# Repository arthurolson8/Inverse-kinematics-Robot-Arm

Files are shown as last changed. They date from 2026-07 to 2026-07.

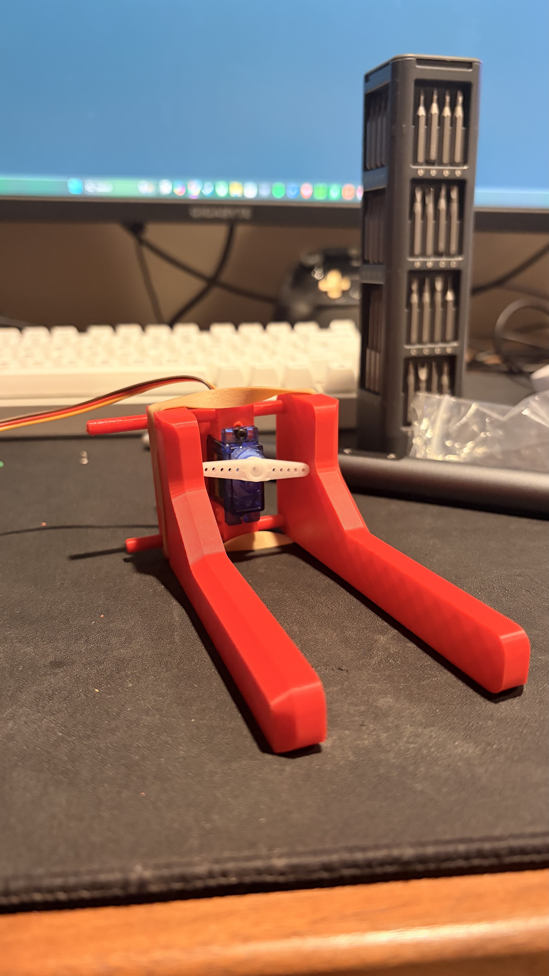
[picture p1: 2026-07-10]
Design Process/Iterations/Gripper/IMG_4110.jpeg

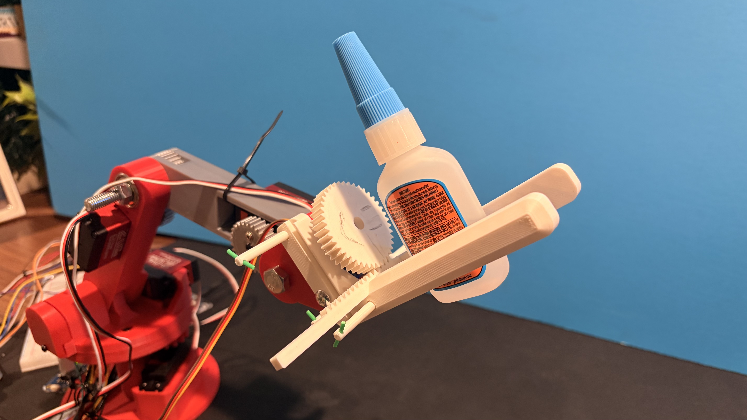
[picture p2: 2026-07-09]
Images/IMG_4085.jpeg

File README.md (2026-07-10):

# Inverse Kinematics Robot Arm

## Overview

This project is a custom-designed 4-degree-of-freedom robotic arm built from the ground up using Solidworks, Arduino, and 3D-printed components. The goal of this project is to develop practical skills in mechanical design, embedded systems, robotics, and control algorithms, and also feel like Tony Stark.
The robot is designed to perform precise pick-and-place operations using inverse kinematics, high-torque servo motors, and a custom rack-and-pinion gripper with auto table leveling.

---

## Objectives

- Design a fully custom robotic arm in SolidWorks
- Manufacture structural components using 3D printing
- Develop an Arduino-based control system
- Implement forward and inverse kinematics
- Create a modular robot that can be expanded with sensors and computer vision (hopefully)
- Document the engineering design process from concept to finished prototype

---

## Features

- Custom 3D-printed mechanical design
- 4 Degrees of Freedom
- Bearing-supported base, shoulder, elbow, and wrist joints
- High-torque DS3218 servos
- SG90 rack-and-pinion gripper
- Arduino Uno R4 WiFi controller
- PCA9685 16-channel servo driver (have not integrated yet)
- Manual joystick control
- Modular electronics design
- Expandable software architecture

Planned Features

- Cartesian position control
- Inverse kinematics
- Autonomous pick-and-place
- Computer vision using OpenCV
- Camera-based object detection
- Object size estimation
- Automatic gripping
- Motion recording and playback

---

### Hardware / Mechanical

- Custom CAD using SolidWorks
- Custom 3D Printed parts using PLA
- 2 M8 60mm Bolts
- 1 M8 50mm Bolt
- 2 M8 Nuts
- Various sizes of M2 and M3 bolts and nuts
- M2 and M8 threaded inserts
- 8 608 ZZ bearings

### Electronics

- Arduino Uno R4 WiFi
- PCA9685 Servo Driver
- breadboard
- 4× DS3218 20kg·cm Servos
- 2× SG90 Micro Servos
- Three Dual-Axis Joysticks (only 2 used for final controls)
- External 5V 10A Power Supply

---

## Software

- Arduino IDE
- C++
- Solidworks
- Git
- GitHub

Future Software

- Python
- OpenCV
- Serial Communication
- Autonomous Motion Planning

---

## Mechanical Design

The arm uses bearing-supported rotating joints to reduce servo loading and improve structural rigidity. The base, elbow, and wrist joints are gear-driven with a 1:1 ratio, while the shoulder joint is direct drive. For the final version of the gripper, I opted for a Rack and pinion design after 2 other past versions.

Major design goals include

- Lightweight construction
- High stiffness
- Modular assemblies
- Easy maintenance
- Minimal backlash
- Manufacturable using hobby-grade 3D printers

---

## Project Status

Current Progress

- [x] Overall robot architecture completed
- [x] CAD design completed
- [x] Mechanical design iterations
- [x] Gear train prototypes
- [x] Manufacturing
- [x] Assembly
- [x] Wiring
- [x] Servo calibration
- [x] Joystick control
- [x] Forward kinematics
- [x] Inverse kinematics
- [ ] Autonomous pick-and-place w computer vison

---

## Design Iterations

Version 1
- Initial geared shoulder joint (gears slipped) with parallel arm gripper
- bearing-supported joints
- heat set inserts

Version 2
- Reinforced the servo mount and made the shoulder direct drive
- Made a gripper with a closing mechanism supported by rubber bands (broke servo)

Version 3 (Current)
- Improved structural rigidity
- Rack-and-pinion gripper
- Modular arm assemblies

Future Versions
- Computer vision
- Force sensing
- Autonomous object sorting

---

## Lessons Learned

Throughout this project, I have gained experience in

- Mechanical design
- CAD modeling
- Design iteration
- Failure analysis
- Rapid prototyping
- Embedded programming
- Robotics
- Electronics integration
- Manufacturing constraints
- Engineering documentation

---

## Possible Future Improvements

- Computer vision
- Camera calibration
- Automatic object detection
- Object size estimation
- Adaptive gripping
- Motion planning
- Closed-loop control
- Force sensing

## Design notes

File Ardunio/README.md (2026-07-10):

# Software Architecture

The robot is controlled by a custom Arduino program written in C++ using the Arduino IDE. Rather than relying on existing robotic arm frameworks, the software was developed specifically for this robot's mechanical design, servo configuration, and joint geometry.

The software is organized around modular subsystems responsible for robot configuration, joint control, joystick input, calibration, gripper control, and inverse kinematics. During development these modules were combined into a single Arduino sketch (`MARK_IV_IK_ARM.ino`) to simplify deployment and debugging.

---
## Control Flow Chart

User Input (Joystick or Camera)
            │
            ▼
Desired Position (X, Y, Z)
            │
            ▼
Inverse Kinematics Solver
            │
            ▼
Joint Angles
            │
            ▼
Servo Calibration Offsets
            │
            ▼
Motion Limiting & Safety Checks
            │
            ▼
Servo Commands
            │
            ▼
Physical Robot Movement

---
# Software Design Philosophy

The primary goals during development were:

- Modular and readable code
- Easy servo calibration
- Smooth joint motion
- Expandability for inverse kinematics
- Support for future autonomous operation

Instead of directly writing servo positions throughout the program, each joint is treated as an independent object with its own limits, speed, home position, and calibration settings. This makes it possible to modify individual joints without rewriting the entire control system.

---

# Robot Configuration

The first section of the program defines the hardware configuration of the robot.

This includes:

- Servo pin assignments
- Joystick analog pins
- Joystick button pins
- Servo home positions
- Motion limits
- Servo directions
- Servo speeds
- Servo pulse widths
- Servo travel ranges

Separating these values from the rest of the code makes it possible to mechanically redesign the robot without changing the control algorithms.

---

# Joint Control

Each joint maintains its own state including:

- Current position
- Target position
- Home position
- Minimum angle
- Maximum angle
- Maximum movement speed
- Servo direction
- Servo type

Every program loop updates each joint independently.

Rather than instantly jumping to the requested angle, each joint moves toward its target position at a controlled speed. This produces smoother motion, reduces shock loading on the gears, and decreases current spikes.

---

# Joystick Control

The robot is manually controlled using three dual-axis joysticks. (But only 2 in Inverse kinematics mode)

The joysticks provide analog control inputs corresponding to the robot's six degrees of freedom.

Each joystick value is read using Arduino analog inputs.

The joystick values are converted into incremental motion commands rather than absolute positions. This allows the servos to hold their current position whenever the joystick returns to center.

Deadbands are implemented around the joystick center position to eliminate unwanted drift caused by analog noise.

---

# Servo Calibration

One of the largest challenges during development was aligning the mathematical model of the robot with the physical servo positions.

Although inverse kinematics computes joint angles mathematically, every servo is mounted differently and has its own mechanical zero position.

To solve this problem, calibration offsets were introduced.

The calibration process consists of:

1. Moving each joint into a known mechanical reference position.
2. Recording the raw servo angle.
3. Comparing the measured position to the desired mathematical angle.
4. Computing an offset for each servo.
5. Applying the offset whenever inverse kinematics calculates a new joint angle.

This allows the inverse kinematics model to remain independent of the physical mounting orientation of each servo.

---

# Motion Limits

Every servo is constrained to safe operating limits.

Before commanding any movement, the requested angle is clamped between predefined minimum and maximum values.

This prevents:

- Mechanical interference
- Gear damage
- Servo overtravel
- Wiring collisions

Software limits provide an additional layer of protection beyond the physical design.

---

# Inverse Kinematics

The long-term objective of the software is to allow the robot to move to any point within its reachable workspace using Cartesian coordinates.

Instead of manually controlling every servo, the operator specifies the desired end-effector position.

For example:

X = 180 mm

Y = 120 mm

Z = 90 mm

The inverse kinematics algorithm calculates the required joint angles for:

- Base rotation
- Shoulder
- Elbow
- Wrist pitch

Wrist Pitch is locked to be level with the table until a button is pressed then it is free to move. When the lick is engaged again it snaps back to normal horizontal position.

These calculated angles are then converted into calibrated servo commands before being sent to the motors.

This approach separates robot motion from individual servo control, making future autonomous operation possible.

---

# Future Autonomous Operation

The software architecture has been designed with future expansion in mind.

Planned capabilities include:

- Camera-based object detection
- Object size estimation
- Automatic pick-and-place
- Motion recording and playback
- Vision-guided positioning
- Adaptive gripping
- Closed-loop control

The modular design allows these features to be added without restructuring the existing software.

---

# Development Process

This software was developed iteratively alongside the mechanical design of the robot.

As each mechanical subsystem was redesigned, the software was updated to accommodate new joint limits, calibration offsets, and transmission configurations.

Several iterations were required before achieving reliable and repeatable motion due to:

- Servo mounting changes
- Gear ratio modifications
- Shoulder joint redesigns
- Mechanical backlash
- Servo calibration refinement

Developing the software in parallel with the hardware provided valuable experience integrating mechanical, electrical, and embedded software systems into a complete robotic platform.

---

# Lessons Learned

This project provided practical experience in:

- Embedded C++ programming
- Arduino development
- Robot kinematics
- Servo calibration
- Motion control
- Electronics integration
- Mechanical-software integration
- Iterative engineering design
- Debugging embedded systems

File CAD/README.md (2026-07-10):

Here are my current CAD files with assemblies and some pictures

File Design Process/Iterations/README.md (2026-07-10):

Overall Design Process
-
My main redesigns happened with the shoulder and the gripper. I had about 3 versions of the gripper and around 4-5 printed shoulder joint designs, and that is why you see the change from silver to red as the robot evolved. The white was just cause I felt like it though.

The current folder holds all my deaign choice explanations besides the gripper and shoulder.

Check out these folders to see my in detail explanations with pictures!

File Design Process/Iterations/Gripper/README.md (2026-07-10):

Gripper Design Process
-
My first Version was a parallel style gripper with 2 gears attached to the gripper fingers that are moved by one servo, this design looked cool but overall had too much slop. Even though it could hold on to things effectivly, the far end of the fingers were a bit weak, it was hard on the servo and the 8 M3 screws nuts would unscrew themselves automatically when the gripper was used, and I didnt want to permanently attatch them with locktight because then the servo would be stuck in there forever.

V1 Problems
- weak towards far end of fingers
- hard on servo

For my second version I made 2 free moving fingers on either side of the center wrist mount that were attached via 3d printed pins. The plan was to have a rubber band around the 2 fingers and the servo arm would be in the middle and extend horizontally to open it and go vertical to close. Unfortunately even if I used the smallest rubber band I could find, it was too much for the servo to open reliably.

V2 Problems
- too much force on servo
- broken servo

For the 3rd Version I slightly modified the V2 by adding a rack and pinon style gear set up to do the open/closing mechanism and mounted the rack to one finger and mounted the other finger to the side of the wrist mount.

V3 problems
- only has one set distance to open to atm
  
Possible solutions
- force sensor on inside of fingers

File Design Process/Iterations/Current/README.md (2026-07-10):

Current Design explanations
-
Because I wanted bearing supported joints for all of the links and base, I decided to make most of the joints gear driven because I could not think of a compact way to have it direct driven with M8 bolts as the joint axises.

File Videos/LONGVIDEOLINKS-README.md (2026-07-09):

Here is a youtube link for the DEMO of the Current Arm :
https://m.youtube.com/watch?v=HJ-uZ0-45NE&pp=ygUhSW52ZXJzZSBraW5lbWF0aWNzIHJvYm90IG1hcmsgSVYg&ra=m

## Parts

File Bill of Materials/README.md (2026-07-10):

# Bill of Materials (BOM)

| Component | Quantity | Purpose |
|---|:---:|---|
| Arduino Uno R4 WiFi | 1 | Main microcontroller |
| PCA9685 16-Channel Servo Driver | 1 | Controls multiple servos |
| DS3218 20kg·cm 270° Servo Motors | 4 | Base, shoulder, elbow, and wrist pitch joints |
| SG90 Micro Servo Motors | 2 | Wrist roll and gripper |
| Dual-Axis Joystick Modules | 3 | Manual robot control |
| 5V 10A DC Power Supply | 1 | External power source for servos |
| DC Barrel Jack Connector Kit | 1 | Power supply connection |
| Breadboard & Jumper Wire Kit | 1 | Prototyping electronics |
| Heat Shrink Tubing Assortment | 1 | Wire insulation and cable management |
| 608ZZ Ball Bearings | 10 | Joint support and reduced friction |
| M3 Screw, Nut & Washer Assortment | 1 Kit | Primary fasteners for printed parts |
| M2 Screw & Nut Assortment | 1 Kit | Small hardware for electronics and gripper assembly |
| M3 Brass Heat-Set Threaded Inserts | 100 | Durable threaded mounting points in 3D printed parts |
| M2 Brass Heat-Set Threaded Inserts | 1 Kit | Threaded inserts for smaller printed components |
| $10 Soldering Iron | 1 | Assembly and electrical connections |

---

## Software

- Arduino IDE
- Solidworks
- GitHub

### Planned Hardware

- Logitech C270 Webcam

### Planned Software

- Python
- OpenCV

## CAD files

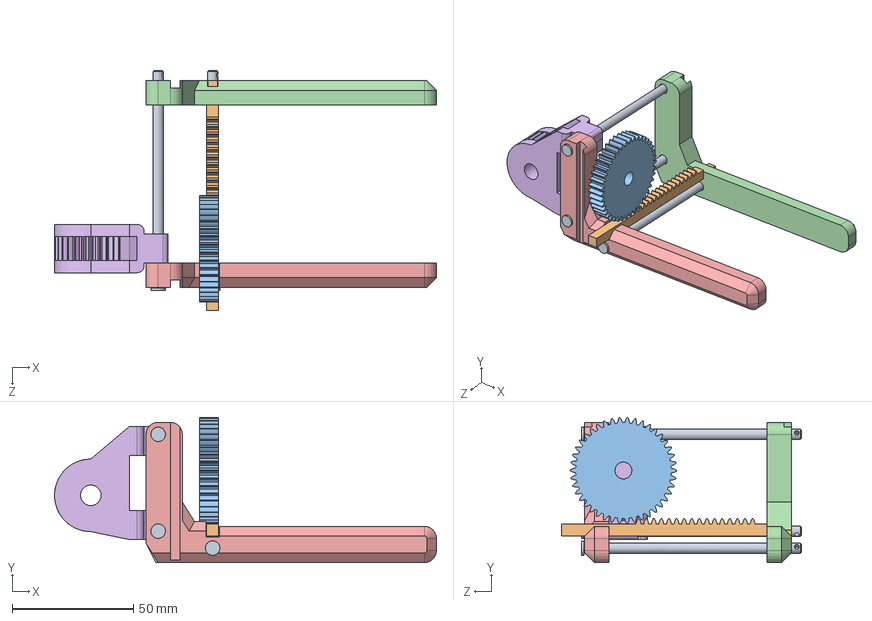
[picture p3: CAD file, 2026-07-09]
Design Process/Iterations/Gripper/NV2 Gripper assem.SLDASM
157.8 x 60.0 x 99.2 mm
Wrist Joint V3
Gripper finger R
Gripper finger L
Gripper gear
Gripper Rack
Gripper pin V2 x 3

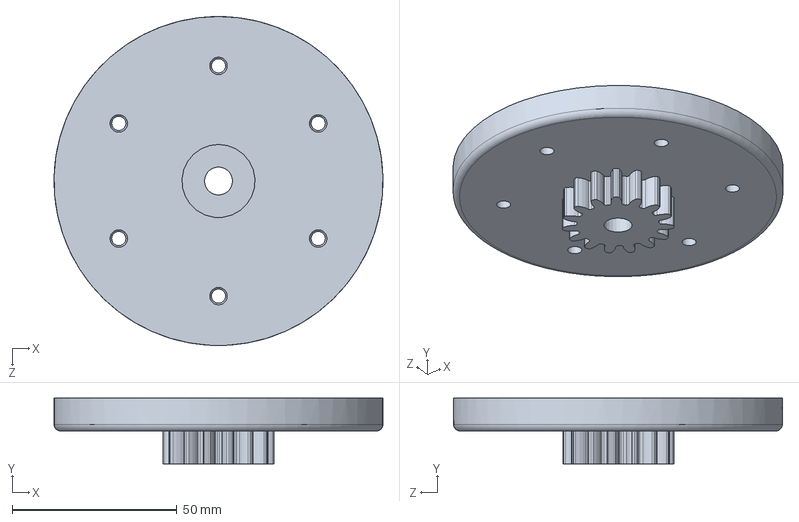
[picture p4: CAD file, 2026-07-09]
CAD/Base/NV1 Base mount.SLDPRT
100.0 x 20.0 x 100.0 mm

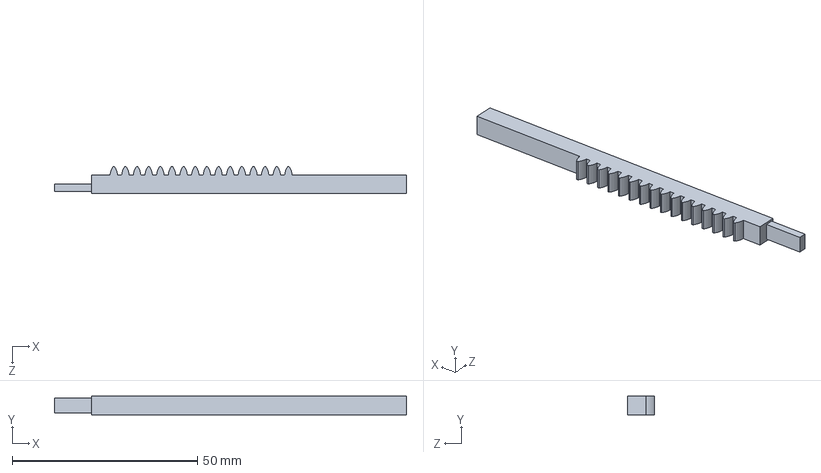
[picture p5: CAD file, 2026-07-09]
CAD/Gripper/Gripper Rack.SLDPRT
95.0 x 5.00 x 7.25 mm

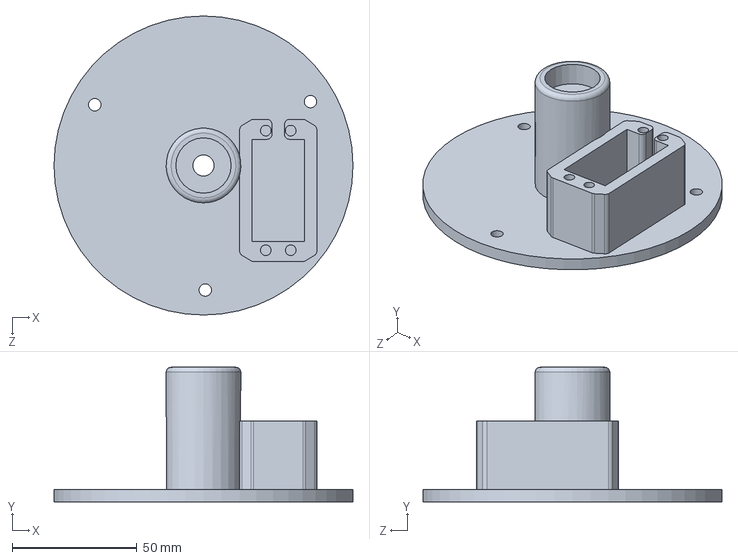
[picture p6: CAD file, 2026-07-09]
CAD/Base/NV1 Standing Base.SLDPRT
120.0 x 54.0 x 120.0 mm

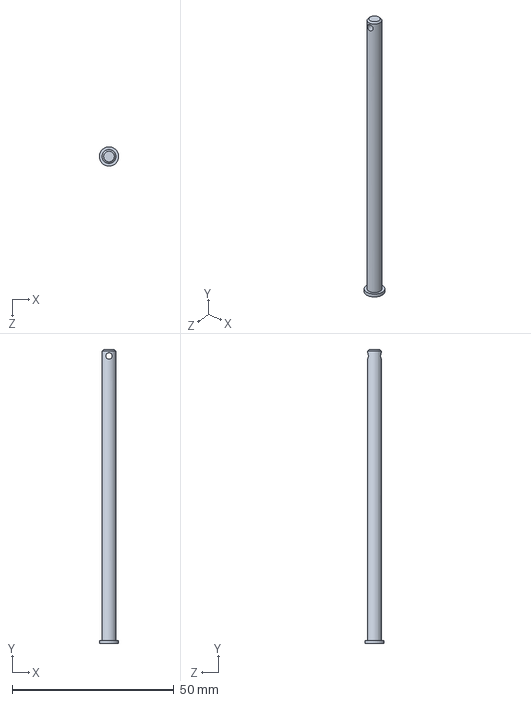
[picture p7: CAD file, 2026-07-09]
CAD/Gripper/Gripper pin V2.SLDPRT
5.99 x 91.0 x 6.00 mm

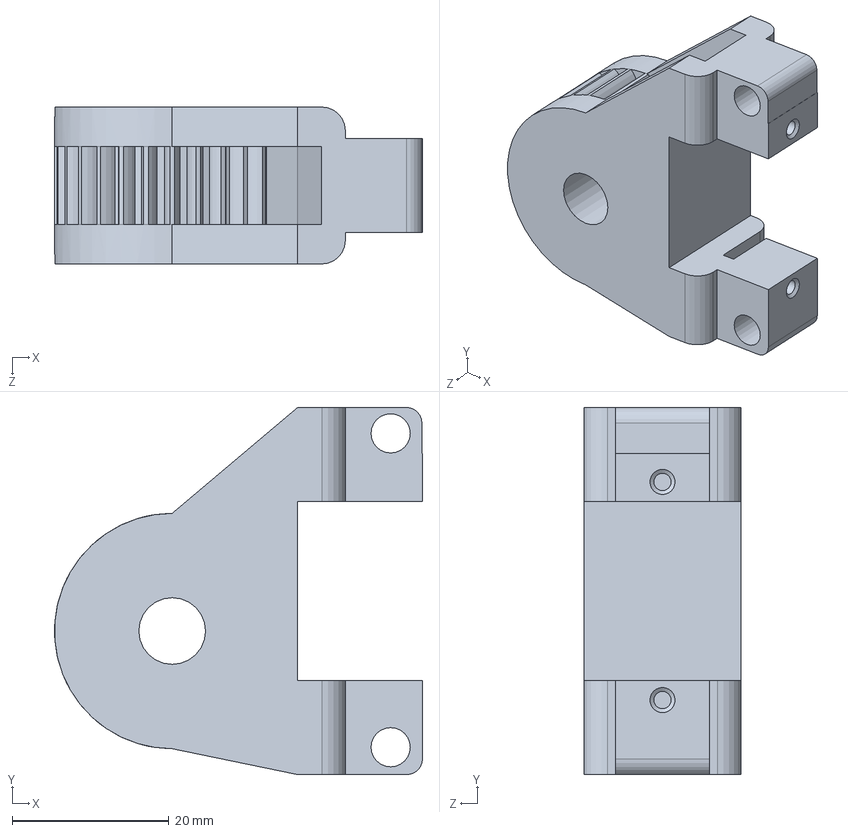
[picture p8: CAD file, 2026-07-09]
CAD/Arm/Wrist Joint V3.SLDPRT
46.9 x 46.8 x 20.0 mm

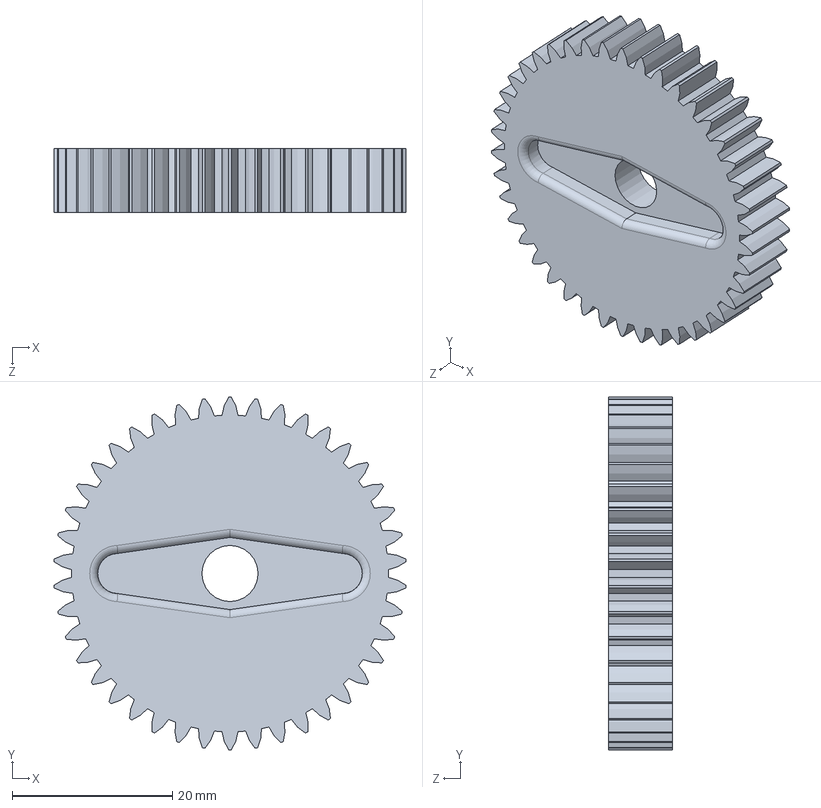
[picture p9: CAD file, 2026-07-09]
CAD/Gripper/Gripper gear.SLDPRT
43.9 x 44.0 x 8.00 mm

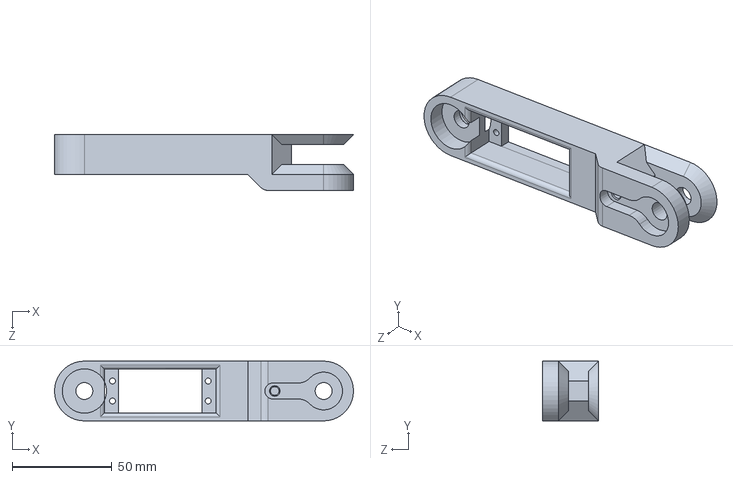
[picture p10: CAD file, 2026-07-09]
CAD/Arm/Direct Drive Bicep Link V1F.SLDPRT
150.0 x 30.0 x 28.0 mm

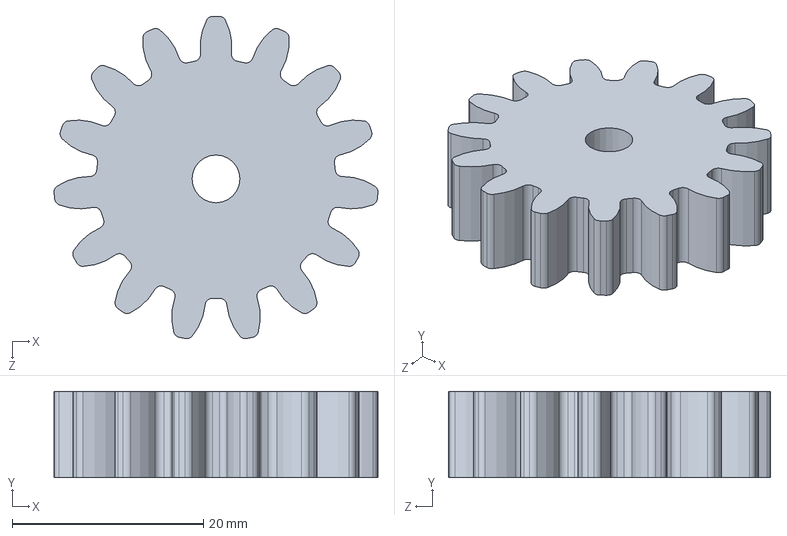
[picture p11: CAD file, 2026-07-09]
CAD/Base/NV1 Base Gear.SLDPRT
33.9 x 9.00 x 33.7 mm

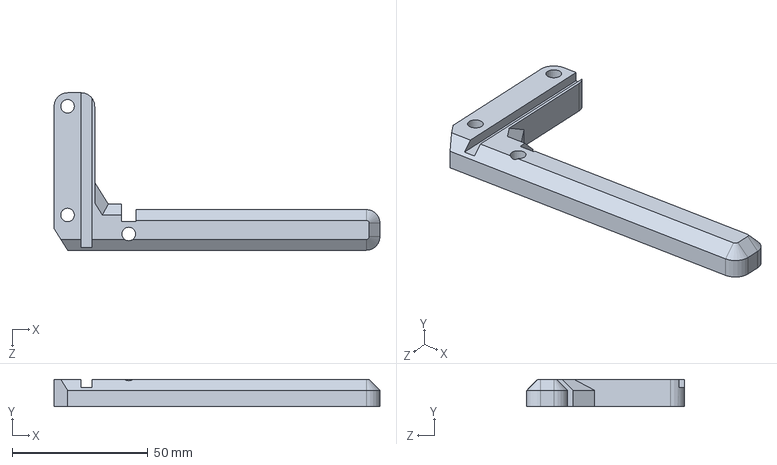
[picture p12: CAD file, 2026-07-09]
CAD/Gripper/Gripper finger R.SLDPRT
120.0 x 10.0 x 58.0 mm

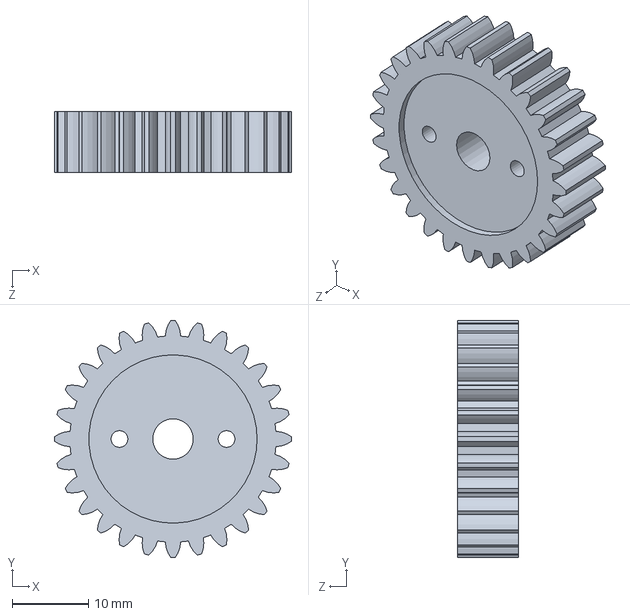
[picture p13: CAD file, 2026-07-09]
CAD/Arm/elbow servo gear.SLDPRT
31.0 x 31.0 x 8.00 mm

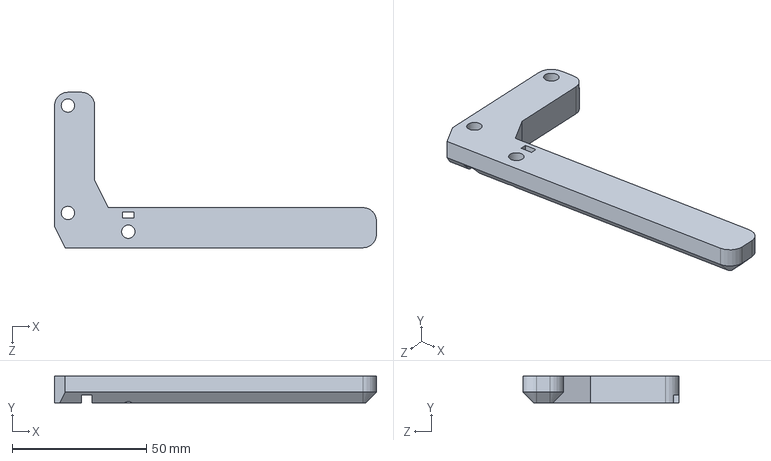
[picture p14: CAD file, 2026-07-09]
CAD/Gripper/Gripper finger L.SLDPRT
120.0 x 10.0 x 58.0 mm

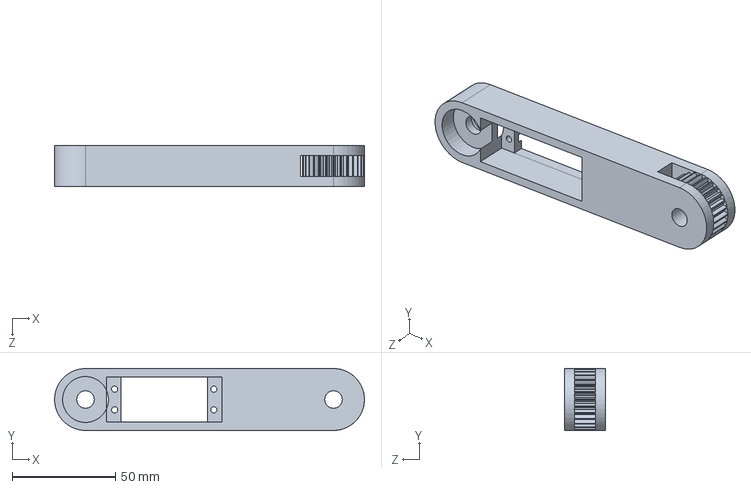
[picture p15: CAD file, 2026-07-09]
CAD/Arm/Forearm Link.SLDPRT
150.0 x 30.0 x 20.0 mm

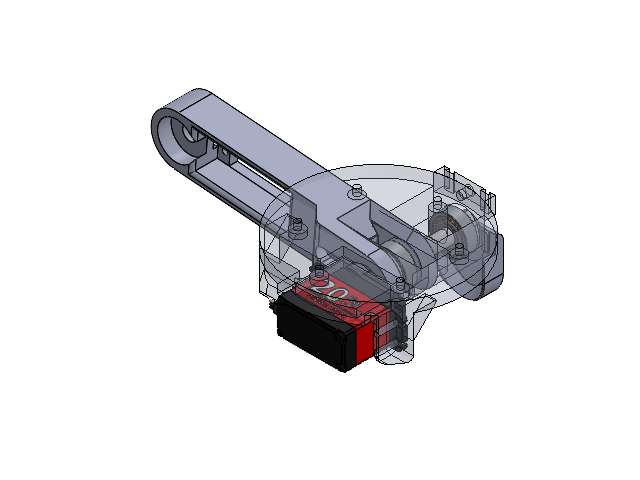
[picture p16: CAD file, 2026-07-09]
Design Process/Iterations/Shoulder Joint/Direct drive Assem.SLDASM
Direct Drive Shoulder Mount V1F
Direct Drive Bicep Link V1F
DS3218MG MS24 Digital Servo 270
p BEARING, METRIC 600 MINIATURE SERIES, DOUBLE-SHIELDED — template Copy x 2
formed hex screw_am
Direct Drive Bolt Cover V1F

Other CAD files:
CAD/Arm/Direct drive Arm Assem.SLDASM
Design Process/Iterations/Gripper/V2 Gripper assem.SLDASM
Design Process/Iterations/Shoulder Joint/Gear shoulder assem.SLDASM
CAD/Base/NV Base Assem.SLDASM
CAD/Arm/Direct Drive Bolt Cover V1F.SLDPRT
CAD/Arm/Direct Drive Shoulder Mount V1F.SLDPRT
Design Process/Iterations/Gripper/OLD V2 Gripper assem.SLDASM
Design Process/Iterations/Old CAD files/OLDARM/Bicep Link V2.SLDPRT
Design Process/Iterations/Old CAD files/OLDARM/Bicep Link.SLDPRT
Design Process/Iterations/Old CAD files/OLDARM/Shoulder base mount V2.SLDPRT
Design Process/Iterations/Old CAD files/OLDARM/Shoulder base mount V4.SLDPRT
Design Process/Iterations/Old CAD files/OLDARM/Shoulder base mount.SLDPRT
Design Process/Iterations/Old CAD files/OLDARM/Wrist Joint gear V2.SLDPRT
Design Process/Iterations/Old CAD files/OLDARM/Wrist Joint gear.SLDPRT
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

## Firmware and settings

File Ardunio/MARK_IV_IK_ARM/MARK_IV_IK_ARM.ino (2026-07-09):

//====================================================================
// Robot_Masterfile.ino
// Single-file build: all modules merged into one sketch file.
// (Config / Joint / Controller / Gripper / Calibration)
//====================================================================

#include <Arduino.h>
#include <Servo.h>
#include <EEPROM.h>
#include <Arduino_Modulino.h>


//====================================================================
// CONFIG
//====================================================================
const byte NUM_JOINTS = 6;
//====================================================
//                  LIBRARIES
//====================================================

#include <Arduino.h>

//====================================================
//                SERVO PINS
//====================================================

const byte BASE_PIN         = 0;
const byte SHOULDER_PIN     = 5;
const byte ELBOW_PIN        = 9;
const byte WRIST_PITCH_PIN  =11;
const byte GRIPPER_PIN   = 13;
const byte UNUSED_SERVO_PIN      = 12;

//====================================================
//             JOYSTICK ANALOG PINS
//====================================================

// Joystick 1
const byte J1_X = A0;
const byte J1_Y = A1;

// Joystick 2
const byte J2_X = A2;
const byte J2_Y = A3;

// Joystick 3
const byte J3_X = A4;
const byte J3_Y = A5;

//====================================================
//          JOYSTICK BUTTON PINS (OPTIONAL)
//====================================================

const byte J1_SW = 3;
const byte J2_SW = 5;
const byte J3_SW = 7;

//====================================================
//              SERVO HOME POSITIONS
//====================================================

// These are the positions the robot moves to on startup.
// Adjust after assembling the arm.

const float BASE_HOME         = 135.0;
const float SHOULDER_HOME     = 156.0;
const float ELBOW_HOME        = 118.0;
const float WRIST_PITCH_HOME  = 206.0;
const float GRIPPER_HOME   = 100.64; // closed
const float UNUSED_SERVO_HOME      = 30.0;

//====================================================
//                SERVO LIMITS
//====================================================

// Degrees

const float BASE_MIN = 0;
const float BASE_MAX = 270;

const float SHOULDER_MIN = 50;
const float SHOULDER_MAX = 220;

const float ELBOW_MIN = 40;
const float ELBOW_MAX = 243;

const float WRIST_PITCH_MIN = 56;
const float WRIST_PITCH_MAX = 223;

const float GRIPPER_MIN = 0;
const float GRIPPER_MAX = 123; // open

const float UNUSED_SERVO_MIN = 20;
const float UNUSED_SERVO_MAX = 105;

//====================================================
//            SERVO DIRECTION
//====================================================

// false = normal
// true = reversed

const bool BASE_REVERSE         = false;
const bool SHOULDER_REVERSE     = false;
const bool ELBOW_REVERSE        = false;
const bool WRIST_PITCH_REVERSE  = false;
const bool GRIPPER_REVERSE   = false;
const bool UNUSED_SERVO_REVERSE      = false;

//====================================================
//              MAX SERVO SPEED
//====================================================

// Degrees moved per update.
// Larger value = faster motion.

const float BASE_SPEED         = .5;
const float SHOULDER_SPEED     = 1;
const float ELBOW_SPEED        = 1.0;
const float WRIST_PITCH_SPEED  = 1.1;
const float GRIPPER_SPEED   = 2;
const float UNUSED_SERVO_SPEED      = 2.0;


//====================================================
// Servo Types
//====================================================

// DS3218 Servos
const float DS3218_RANGE = 270.0;

// SG90 Servos
const float SG90_RANGE = 180.0;


//====================================================
// Pulse Widths
//====================================================

// DS3218
const int DS3218_MIN_US = 500;
const int DS3218_MAX_US = 2500;

// SG90
const int SG90_MIN_US = 500;
const int SG90_MAX_US = 2400;

//====================================================
//             JOYSTICK SETTINGS
//====================================================

const int DEADZONE = 60;

// These will be calibrated automatically
// during startup.

extern int J1_X_CENTER;
extern int J1_Y_CENTER;

extern int J2_X_CENTER;
extern int J2_Y_CENTER;

extern int J3_X_CENTER;
extern int J3_Y_CENTER;

//====================================================
//             SERVO PWM CALIBRATION
//====================================================

// Most DS3218 servos work well with these.
// We'll fine tune later if necessary.

const int SERVO_MIN_US = 500;
const int SERVO_MAX_US = 2500;

//====================================================
//               DEBUG OPTIONS
//====================================================

const bool ENABLE_SERIAL_DEBUG = true;


//====================================================
// Number of Joints
//====================================================


// Joint Numbers

enum JointID
{
    BASE = 0,
    SHOULDER,
    ELBOW,
    WRIST_PITCH,
    GRIPPER,
    UNUSED_SERVO
};
//====================================================
// JOINT CONFIGURATION (ARRAY-BASED)
//====================================================

const byte servoPins[NUM_JOINTS] =
{
    BASE_PIN,
    SHOULDER_PIN,
    ELBOW_PIN,
    WRIST_PITCH_PIN,
    GRIPPER_PIN,
    UNUSED_SERVO_PIN
};

const float homePositions[NUM_JOINTS] =
{
    BASE_HOME,
    SHOULDER_HOME,
    ELBOW_HOME,
    WRIST_PITCH_HOME,
    GRIPPER_HOME,
    UNUSED_SERVO_HOME
};

const float minAngles[NUM_JOINTS] =
{
    BASE_MIN,
    SHOULDER_MIN,
    ELBOW_MIN,
    WRIST_PITCH_MIN,
    GRIPPER_MIN,
    UNUSED_SERVO_MIN
};

const float maxAngles[NUM_JOINTS] =
{
    BASE_MAX,
    SHOULDER_MAX,
    ELBOW_MAX,
    WRIST_PITCH_MAX,
    GRIPPER_MAX,
    UNUSED_SERVO_MAX
};

const float servoSpeeds[NUM_JOINTS] =
{
    BASE_SPEED,
    SHOULDER_SPEED,
    ELBOW_SPEED,
    WRIST_PITCH_SPEED,
    GRIPPER_SPEED,
    UNUSED_SERVO_SPEED
};

const bool servoReverse[NUM_JOINTS] =
{
    BASE_REVERSE,
    SHOULDER_REVERSE,
    ELBOW_REVERSE,
    WRIST_PITCH_REVERSE,
    GRIPPER_REVERSE,
    UNUSED_SERVO_REVERSE
};

const float servoRange[NUM_JOINTS] =
{
    DS3218_RANGE,
    DS3218_RANGE,
    DS3218_RANGE,
    DS3218_RANGE,
    SG90_RANGE,
    SG90_RANGE
};

const int servoMinPulse[NUM_JOINTS] =
{
    DS3218_MIN_US,
    DS3218_MIN_US,
    DS3218_MIN_US,
    DS3218_MIN_US,
    SG90_MIN_US,
    SG90_MIN_US
};

const int servoMaxPulse[NUM_JOINTS] =
{
    DS3218_MAX_US,
    DS3218_MAX_US,
    DS3218_MAX_US,
    DS3218_MAX_US,
    SG90_MAX_US,
    SG90_MAX_US
};
enum RobotMode
{
    MODE_NORMAL,
    MODE_CALIBRATION,
    MODE_IK_ARM
};

extern RobotMode currentMode;

//====================================================================
// JOINT (declaration)
//====================================================================
#include <Arduino.h>
#include <Servo.h>
class Joint
{
private:

    Servo servo;

    byte pin;

    float position;
    float homePosition;

    float minimumAngle;
    float maximumAngle;

    float speed;

    bool reverse;

    float servoRange;

    int minPulse;
    int maxPulse;

public:

    Joint();

    void begin(
        byte servoPin,
        float home,
        float minimum,
        float maximum,
        float maxSpeed,
        bool reversed,
        float rangeDegrees,
        int minMicroseconds,
        int maxMicroseconds
    );

    void update(int joystickValue, int joystickCenter);

    void write();

    void hold();

    void home();

    void setPosition(float newPosition);

    float getPosition();

    void setSpeed(float newSpeed);

    void setReverse(bool state);

    void setLimits(float minimum,float maximum);

    float getMinLimit();

    float getMaxLimit();
};

// Global robot joints
extern Joint joints[NUM_JOINTS];

//====================================================================
// JOINT (implementation)
//====================================================================
//====================================================
// Global Joint Array
//====================================================

Joint joints[NUM_JOINTS];

//====================================================
// Constructor
//====================================================

Joint::Joint()
{
    pin = 0;

    position = 90.0;
    homePosition = 90.0;

    minimumAngle = 0.0;
    maximumAngle = 180.0;

    speed = 1.0;

    reverse = false;

    servoRange = 180.0;

    minPulse = 500;
    maxPulse = 2500;
}

//====================================================
// Begin
//====================================================

void Joint::begin(
    byte servoPin,
    float home,
    float minimum,
    float maximum,
    float maxSpeed,
    bool reversed,
    float rangeDegrees,
    int minMicroseconds,
    int maxMicroseconds
)
{
    pin = servoPin;

    homePosition = home;
    position = home;

    minimumAngle = minimum;
    maximumAngle = maximum;

    speed = maxSpeed;

    reverse = reversed;

    servoRange = rangeDegrees;

    minPulse = minMicroseconds;
    maxPulse = maxMicroseconds;

    servo.attach(pin, minPulse, maxPulse);

    write();
}

//====================================================
// Update Joint
//====================================================

void Joint::update(int joystickValue, int joystickCenter)
{
    int offset = joystickValue - joystickCenter;

    if (abs(offset) <= DEADZONE)
        return;

    float multiplier =
        (float)(abs(offset) - DEADZONE) /
        (512.0 - DEADZONE);

    multiplier = constrain(multiplier, 0.0f, 1.0f);

    float movement = multiplier * speed;

    if (reverse)
        movement = -movement;

    if (offset > 0)
        position += movement;
    else
        position -= movement;

    position = constrain(position, minimumAngle, maximumAngle);
}

//====================================================
// Hold Position
//====================================================

void Joint::hold()
{
    write();
}

//====================================================
// Home Position
//====================================================

void Joint::home()
{
    position = homePosition;
    write();
}

//====================================================
// Write Servo
//====================================================

void Joint::write()
{
    int pulse = map(
        (long)(position * 10),
        0,
        (long)(servoRange * 10),
        minPulse,
        maxPulse
    );

    servo.writeMicroseconds(pulse);
}

//====================================================
// Set Position
//====================================================

void Joint::setPosition(float newPosition)
{
    position = constrain(newPosition, minimumAngle, maximumAngle);
}

//====================================================
// Get Position
//====================================================

float Joint::getPosition()
{
    return position;
}

//====================================================
// Set Speed
//====================================================

void Joint::setSpeed(float newSpeed)
{
    speed = newSpeed;
}

//====================================================
// Reverse Direction
//====================================================

void Joint::setReverse(bool state)
{
    reverse = state;
}

//====================================================
// Set Limits
//====================================================

void Joint::setLimits(float minimum, float maximum)
{
    minimumAngle = minimum;
    maximumAngle = maximum;

    position = constrain(position, minimumAngle, maximumAngle);
}

//====================================================
// Get Limits
//====================================================

float Joint::getMinLimit()
{
    return minimumAngle;
}

float Joint::getMaxLimit()
{
    return maximumAngle;
}

//====================================================================
// CONTROLLER (declaration)
//====================================================================
#include <Arduino.h>

//====================================================
//      Global joystick center values
//====================================================

extern int J1_X_CENTER;
extern int J1_Y_CENTER;

extern int J2_X_CENTER;
extern int J2_Y_CENTER;

extern int J3_X_CENTER;
extern int J3_Y_CENTER;

//====================================================
//      Functions
//====================================================

// Reads joystick centers during startup
void calibrateJoysticks();

// Optional debug print
void printJoystickValues();

//====================================================================
// CONTROLLER (implementation)
//====================================================================
//====================================================
//      Center Values
//====================================================

int J1_X_CENTER = 512;
int J1_Y_CENTER = 512;

int J2_X_CENTER = 512;
int J2_Y_CENTER = 512;

int J3_X_CENTER = 512;
int J3_Y_CENTER = 512;

//====================================================
//      Calibrate Joysticks
//====================================================

void calibrateJoysticks()
{
    long j1x = 0;
    long j1y = 0;

    long j2x = 0;
    long j2y = 0;

    long j3x = 0;
    long j3y = 0;

    const int samples = 100;

    Serial.println();
    Serial.println("Calibrating Joysticks...");
    Serial.println("Don't touch the joysticks!");

    delay(1000);

    for(int i = 0; i < samples; i++)
    {
        j1x += analogRead(J1_X);
        j1y += analogRead(J1_Y);

        j2x += analogRead(J2_X);
        j2y += analogRead(J2_Y);

        j3x += analogRead(J3_X);
        j3y += analogRead(J3_Y);

        delay(5);
    }

    J1_X_CENTER = j1x / samples;
    J1_Y_CENTER = j1y / samples;

    J2_X_CENTER = j2x / samples;
    J2_Y_CENTER = j2y / samples;

    J3_X_CENTER = j3x / samples;
    J3_Y_CENTER = j3y / samples;

    Serial.println("Done!");
    Serial.println();

    printJoystickValues();
}

//====================================================
//      Debug
//====================================================

void printJoystickValues()
{
    Serial.println("Joystick Centers");

    Serial.print("J1 X: ");
    Serial.println(J1_X_CENTER);

    Serial.print("J1 Y: ");
    Serial.println(J1_Y_CENTER);

    Serial.print("J2 X: ");
    Serial.println(J2_X_CENTER);

    Serial.print("J2 Y: ");
    Serial.println(J2_Y_CENTER);

    Serial.print("J3 X: ");
    Serial.println(J3_X_CENTER);

    Serial.print("J3 Y: ");
    Serial.println(J3_Y_CENTER);

    Serial.println();
}

//====================================================================
// UNUSED KNOB CONTROLLER (declaration) -- leftover from the old knob-driven gripper, kept but never called
//====================================================================
#include <Arduino.h>
#include <Arduino_Modulino.h>

class UnusedKnobController
{
private:

    ModulinoKnob knob;

    int lastKnobValue;

public:

    UnusedKnobController();

    void begin();

    void update();

    // Returns true once each time the knob is clicked
    bool buttonPressed();

    // Returns the current encoder position
    int knobPosition();
};

extern UnusedKnobController unusedKnobController;

//====================================================================
// UNUSED KNOB CONTROLLER (implementation)
//====================================================================
UnusedKnobController unusedKnobController;

//====================================================
// Constructor
//====================================================

UnusedKnobController::UnusedKnobController()
{
    lastKnobValue = 0;
}

//====================================================
// Begin
//====================================================

void UnusedKnobController::begin()
{
    Modulino.begin();

    knob.begin();

    lastKnobValue = knob.get();
}

//====================================================
// Update
//====================================================

void UnusedKnobController::update()
{
    int value = knob.get();

    int change = value - lastKnobValue;

    if(change != 0)
    {
        float pos = joints[UNUSED_SERVO].getPosition();

        pos += change * UNUSED_SERVO_SPEED;

        joints[UNUSED_SERVO].setPosition(pos);

        lastKnobValue = value;
    }

    joints[UNUSED_SERVO].write();
}

//====================================================
// Returns true once when the knob button is clicked
//====================================================

bool UnusedKnobController::buttonPressed()
{
    return knob.isPressed();
}

//====================================================
// Returns current knob encoder position
//====================================================

int UnusedKnobController::knobPosition()
{
    return knob.get();
}

//====================================================================
// CALIBRATION (declaration)
//====================================================================
#include <Arduino.h>

// Call once in setup(), AFTER joints[] have been begin()'d and
// AFTER unusedKnobController.begin(). Loads any previously saved
// limits from EEPROM and applies them to the joints. Also checks
// whether the knob button is being held down, and if so, enters
// calibration mode instead of continuing to home position.
void calibrationInit();

// Call every loop() iteration while currentMode == MODE_CALIBRATION.
void calibrationUpdate();

// Call every loop() iteration while currentMode == MODE_NORMAL.
// Lets you enter Calibration Mode by typing 'c' + Enter, or
// IK Test Mode by typing 'i' + Enter, over Serial. Typing
// 'p' + Enter prints current raw joint angles (read-only,
// doesn't affect calibration or EEPROM) -- handy for finding
// physical reference poses while jogging with the joystick.
void checkSerialModeEntry();

//====================================================================
// CALIBRATION (implementation)
//====================================================================
#include <EEPROM.h>
#include <Arduino_Modulino.h>


ModulinoKnob calibrationKnob;

//--------------------------------------------------
// Internal state
//--------------------------------------------------

static int currentServo = 0;

// Limits found during THIS calibration session.
static float minimumReached[NUM_JOINTS];
static float maximumReached[NUM_JOINTS];

static unsigned long lastPrint = 0;

// Edge-detection for the knob button
static bool wasPressed = false;
static unsigned long pressStart = 0;

const unsigned long LONG_PRESS_MS = 2000;
const unsigned long ENTRY_HOLD_MS = 2000;
const unsigned long ENTRY_WINDOW_MS = 3000;

//--------------------------------------------------

const char* servoNames[NUM_JOINTS] =
{
    "BASE",
    "SHOULDER",
    "ELBOW",
    "WRIST PITCH",
    "GRIPPER",
    "UNUSED SERVO"
};

//--------------------------------------------------
// EEPROM layout
//--------------------------------------------------
// [0]              magic byte (0xA5 = valid data present)
// [1 .. ]           NUM_JOINTS floats: calibrated min angles
// [1 + 4*N .. ]     NUM_JOINTS floats: calibrated max angles

const int EEPROM_MAGIC_ADDR = 0;
const byte EEPROM_MAGIC_VALUE = 0xA5;
const int EEPROM_MIN_ADDR = 1;
const int EEPROM_MAX_ADDR = EEPROM_MIN_ADDR + (NUM_JOINTS * sizeof(float));

//--------------------------------------------------

void printCurrentServo()
{
    Serial.println();
    Serial.println("==============================");
    Serial.print("Calibration Servo: ");
    Serial.println(servoNames[currentServo]);

    Serial.print("Angle: ");
    Serial.println(joints[currentServo].getPosition());

    Serial.println("Rotate Joystick 1 X to move this joint");
    Serial.println("Click Modulino Button   = Save + Next Servo");
    Serial.println("Hold Modulino Button 2s = Save + Exit Calibration");
    Serial.println("==============================");
}

//--------------------------------------------------
// Apply this session's found min/max into the joints
//--------------------------------------------------

void applyLimitsToJoints()
{
    for (int i = 0; i < NUM_JOINTS; i++)
    {
        joints[i].setLimits(minimumReached[i], maximumReached[i]);
    }
}

//--------------------------------------------------
// Persist all limits to EEPROM
//--------------------------------------------------

void writeLimitsToEEPROM()
{
    EEPROM.update(EEPROM_MAGIC_ADDR, EEPROM_MAGIC_VALUE);

    int addr = EEPROM_MIN_ADDR;
    for (int i = 0; i < NUM_JOINTS; i++)
    {
        EEPROM.put(addr, minimumReached[i]);
        addr += sizeof(float);
    }

    addr = EEPROM_MAX_ADDR;
    for (int i = 0; i < NUM_JOINTS; i++)
    {
        EEPROM.put(addr, maximumReached[i]);
        addr += sizeof(float);
    }

    Serial.println("Calibration saved to EEPROM.");
}
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
void loop()
{
    if(currentMode == MODE_NORMAL)
    {
        // MODE_NORMAL is now just an idle/menu state -- it doesn't
        // move any joints. Direct per-joint joystick control only
        // happens inside Calibration Mode (one joint at a time).
        // From here, type 'c' to calibrate or 'k' to enter IK Arm
        // Mode (which is also where the robot starts up by default).
        checkSerialModeEntry();
    }
    else if (currentMode == MODE_CALIBRATION)
    {
        calibrationUpdate();
    }
    else if (currentMode == MODE_IK_ARM)
    {
        ikArmUpdate();
    }

    delay(10);
}



// Serial Monitor COMMANDS =========================
//C-enter calibration mode =  short click->Next, long clock->save
//i-enter IK test mode  = 1-5-> preset target, y-> actually move arm, h-> home, x-> exit IK immediately
//p Print current raw anggle of all 6 joints

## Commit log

2026-07-09 Create Gripper
2026-07-09 Create Shoulder Joint
2026-07-09 Rename CAD/Gripper/Screenshot 2026-07-09 180214.png to CAD/Gripper screenshot
2026-07-09 Rename CAD/Gripper screenshot to CAD/Gripper/Gripper screenshot
2026-07-09 Rename Screenshot 2026-07-08 232828.png to Full Arm Screenshot
2026-07-09 Rename NEW Gripper assem.SLDASM to V2 Gripper assem.SLDASM
    [V2 Gripper assem.SLDASM]
2026-07-09 Rename V2 Gripper assem.SLDASM to OLD V2 Gripper assem.SLDASM
    [OLD V2 Gripper assem.SLDASM]
